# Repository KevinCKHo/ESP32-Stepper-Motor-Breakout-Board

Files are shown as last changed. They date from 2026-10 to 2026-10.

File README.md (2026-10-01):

# ESP32 Stepper Motor Breakout Board

A Wi-Fi controlled, 4-axis stepper motor controller built around an ESP32 on a custom breakout PCB. It was designed to drive a motorized microscope stage (the *Microscope Stage Mover*). 

The ESP32 creates its own Wi-Fi access point and serves a web dashboard. From the dashboard you can jog each axis with sliders, trigger an emergency stop, and watch temperature and humidity live.

<p align="center">
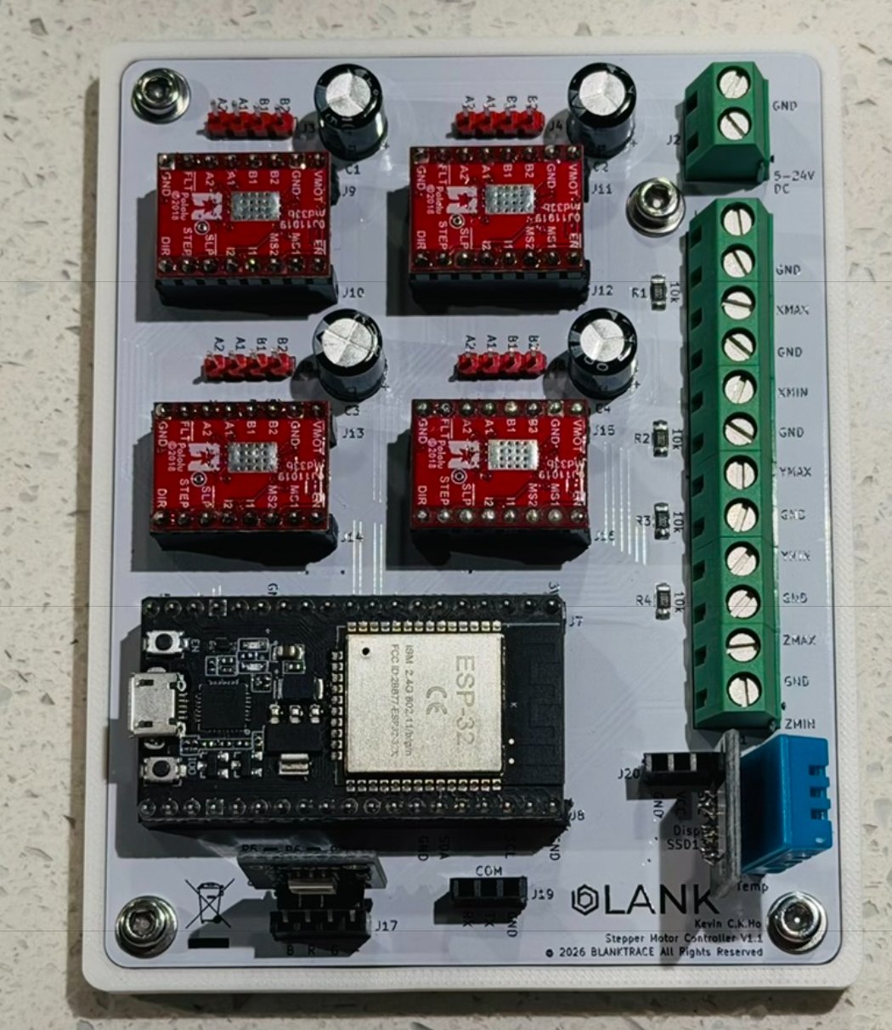
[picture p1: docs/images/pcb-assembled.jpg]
Assembled board with ESP32 and four MP6500 drivers
  
</p>

## Repository layout
| Folder | Contents |
|---|---|
| [`firmware/`](firmware) | PlatformIO project for the ESP32 (Arduino framework) |
| [`hardware/`](hardware) | KiCad 10 project for the *ESP32 Stepper Breakout Board* (schematic, PCB) |
| [`hardware/gerbers/`](hardware/gerbers) | Gerber and drill files (rev V1.1), ready to upload to a PCB fab |
| [`docs/images/`](docs/images) | Pinout, render, and board photos |

## Features
- Up to 4 stepper axes (X, Y, Z plus an optional 4th axis enabled from the UI) using Pololu-style **MP6500** driver carriers
- Variable speed and direction for each axis through slider control in the web UI
- 6 limit switches (X/Y/Z min and max) that stop motion in the triggered direction
- Software emergency stop
- **Thermal stop**: a DHT11 sensor halts all motors above 40 °C
- RGB status LED
- 5–24 V DC motor supply input on a screw terminal

## Hardware: ESP32 Stepper Breakout Board (V1.1)
An 85 × 110 mm, 2-layer board.

| JLCPCB render | Bare PCB |
|---|---|
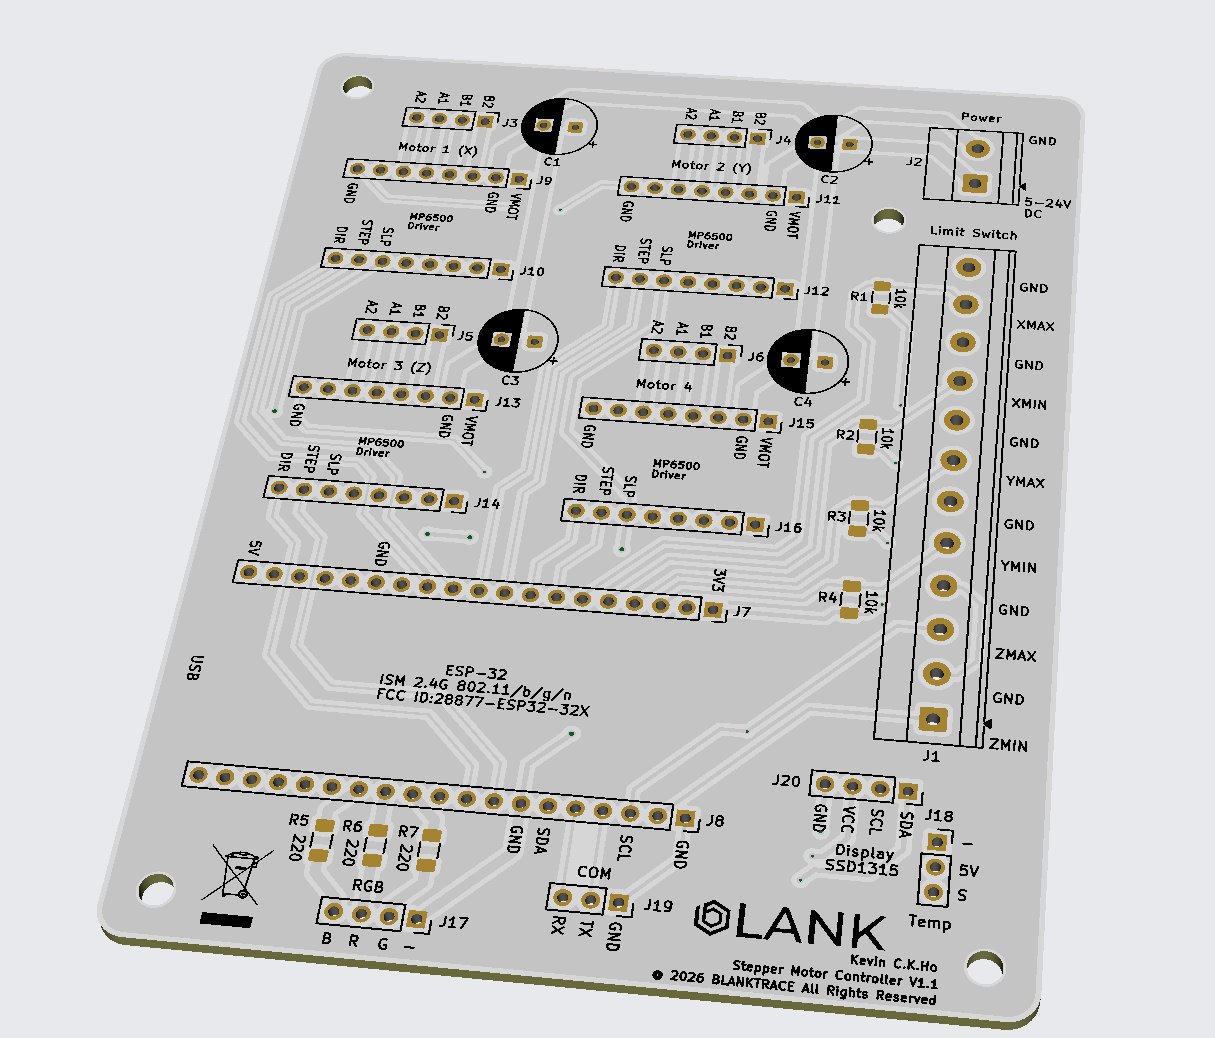
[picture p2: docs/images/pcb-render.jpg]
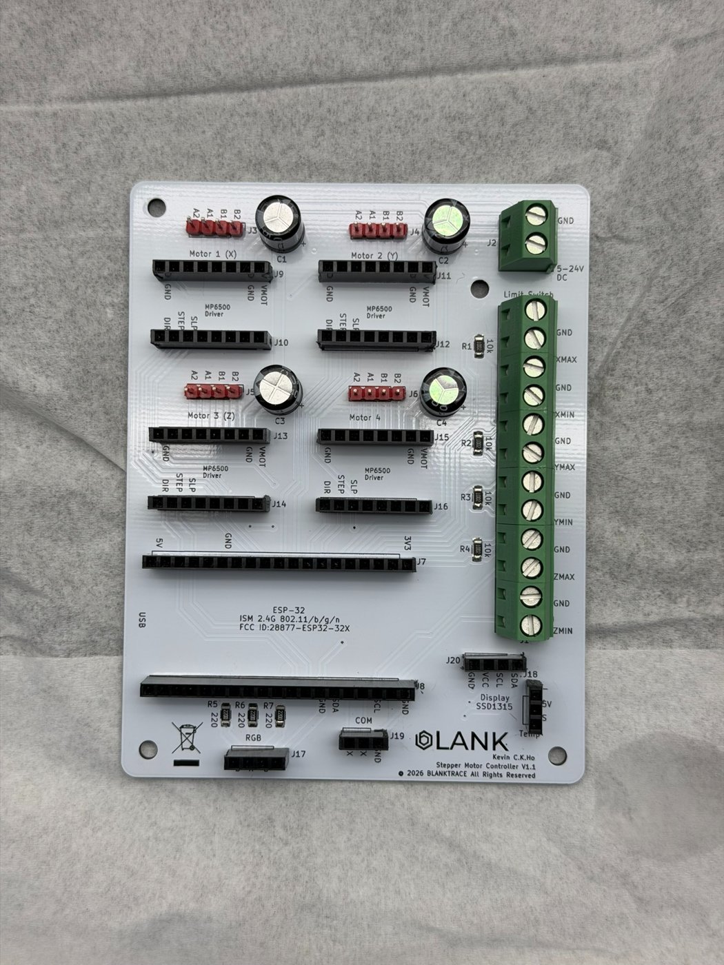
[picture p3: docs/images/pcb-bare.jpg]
|  |  |

**Main connectors**
| Ref | Function |
|---|---|
| J7, J8 | ESP32 DevKit (30-pin) sockets |
| J9–J16 | 4 × MP6500 driver sockets (Motor 1 X, Motor 2 Y, Motor 3 Z, Motor 4) |
| J3–J6 | Motor outputs (A2 A1 B1 B2) |
| C1–C4 | Bulk capacitors on VMOT for each driver |
| J2 | Motor power, 5–24 V DC |
| J1 | 12-way limit-switch terminal (switch to GND) |
| J17 | RGB LED (B R G −) with 220 Ω resistors R5–R7 |
| J18 | Temperature sensor (DHT11) |
| J19 | Serial COM (RX TX GND) |
| J20 | I²C display (SSD1315) |

R1–R4 are 10 kΩ pull-ups for limit inputs on GPIO 34/35/36/39. Those pins have no internal pull-ups.

### ESP32 pin map
ESP32 pin map

| Function | GPIO |
|---|---|
| Motor 1 (X): STEP / DIR | 27 / 14 |
| Motor 2 (Y): STEP / DIR | 25 / 26 |
| Motor 3 (Z): STEP / DIR | 19 / 18 |
| Motor 4: STEP / DIR | 32 / 33 |
| X MIN / X MAX | 34 / 35 |
| Y MIN / Y MAX | 36 (SVP) / 39 (SVN) |
| Z MIN / Z MAX | 23 / 22 |
| RGB LED: R / G / B | 16 / 17 / 4 |
| DHT11 data | 21 |
| I²C display SDA / SCL | 21 / 22 (shared with DHT11 and Z MAX) |

## Bill of materials
Also available as [`docs/BOM.csv`](docs/BOM.csv).

| Qty | Ref | Part | MPN / Source |
|---:|---|---|---|
| 1 | J7, J8 | ESP32 ESP-32D development board (30-pin DevKit) | [Amazon](https://www.amazon.com/dp/B0C8HDDNLV) |
| 4 | J9–J16 | MP6500 stepper motor driver carrier | [Pololu #2968](https://www.pololu.com/product/2968) |
| 1 | J18 | Keyes DHT11 temperature & humidity module | — |
| 1 | J17 | Keyes KY-009 3-colour RGB LED module | — |
| 4 | C1–C4 | 100 µF 50 V electrolytic capacitor | — |
| 4 | R1–R4 | 10 kΩ 1% ¼ W, 1206 (limit-switch pull-ups) | Stackpole RMCF1206FT10K0 |
| 3 | R5–R7 | 220 Ω 1% ¼ W, 1206 (RGB LED) | Stackpole RMCF1206FT220R |
| 1 | J1 | Terminal block, 12-pos, 5 mm, side entry | Phoenix Contact 1715129 |
| 1 | J2 | Terminal block, 2-pos, 5 mm, side entry | Phoenix Contact 1715022 |
| 2 | J7, J8 | Female header 1×19, 2.54 mm (ESP32 socket) | — |
| 8 | J9–J16 | Female header 1×8, 2.54 mm (driver sockets) | — |
| 2 | J17, J20 | Female header 1×4, 2.54 mm (RGB / display) | — |
| 2 | J18, J19 | Female header 1×3, 2.54 mm (temp sensor / COM) | — |
| 4 | J3–J6 | Male pin header 1×4, 2.54 mm (motor outputs) | — |

Optional: SSD1315 0.96" I²C OLED display on J20.

## Firmware
Built with [PlatformIO](https://platformio.org/) (VS Code extension).

1. Open the `firmware/` folder in VS Code with PlatformIO installed.
2. Connect the ESP32 over USB and click **Upload**.
3. On your phone or PC, join the Wi-Fi network **`ESP32-Stepper-System2`**. The password is set in `src/main.cpp`; change it before you deploy.
4. Browse to **http://192.168.4.1** to open the control dashboard.

Libraries (installed automatically): Adafruit DHT sensor library, Adafruit Unified Sensor.

## Ordering the PCB
Upload `hardware/gerbers/ESP32 Stepper break out board V1.1.zip` to JLCPCB, PCBWay, or any other fab. Default 2-layer, 1.6 mm settings are fine.

## Author
Kevin C.K. Ho, BLANKTRACE © 2026

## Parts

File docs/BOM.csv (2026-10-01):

Qty | Reference | Description | Manufacturer Part Number | Manufacturer | Link
1 | J7 J8 | ESP32 ESP-32D development board (30-pin DevKit) |  |  | https://www.amazon.com/dp/B0C8HDDNLV
4 | J9-J16 | MP6500 stepper motor driver carrier | 2968 | Pololu | https://www.pololu.com/product/2968
1 | J18 | DHT11 temperature & humidity sensor module | DHT11 | Keyes
1 | J17 | 3-colour RGB LED module | KY-009 | Keyes
4 | C1-C4 | 100 µF 50 V electrolytic capacitor
4 | R1-R4 | 10 kΩ 1% 1/4 W resistor 1206 (limit switch pull-ups) | RMCF1206FT10K0 | Stackpole
3 | R5-R7 | 220 Ω 1% 1/4 W resistor 1206 (RGB LED) | RMCF1206FT220R | Stackpole
1 | J1 | Terminal block 12-pos 5 mm side entry | 1715129 | Phoenix Contact
1 | J2 | Terminal block 2-pos 5 mm side entry | 1715022 | Phoenix Contact
2 | J7 J8 | Female header 1x19 2.54 mm (ESP32 socket)
8 | J9-J16 | Female header 1x8 2.54 mm (driver sockets)
2 | J17 J20 | Female header 1x4 2.54 mm (RGB / display)
2 | J18 J19 | Female header 1x3 2.54 mm (temp sensor / COM)
4 | J3-J6 | Male pin header 1x4 2.54 mm (motor outputs)

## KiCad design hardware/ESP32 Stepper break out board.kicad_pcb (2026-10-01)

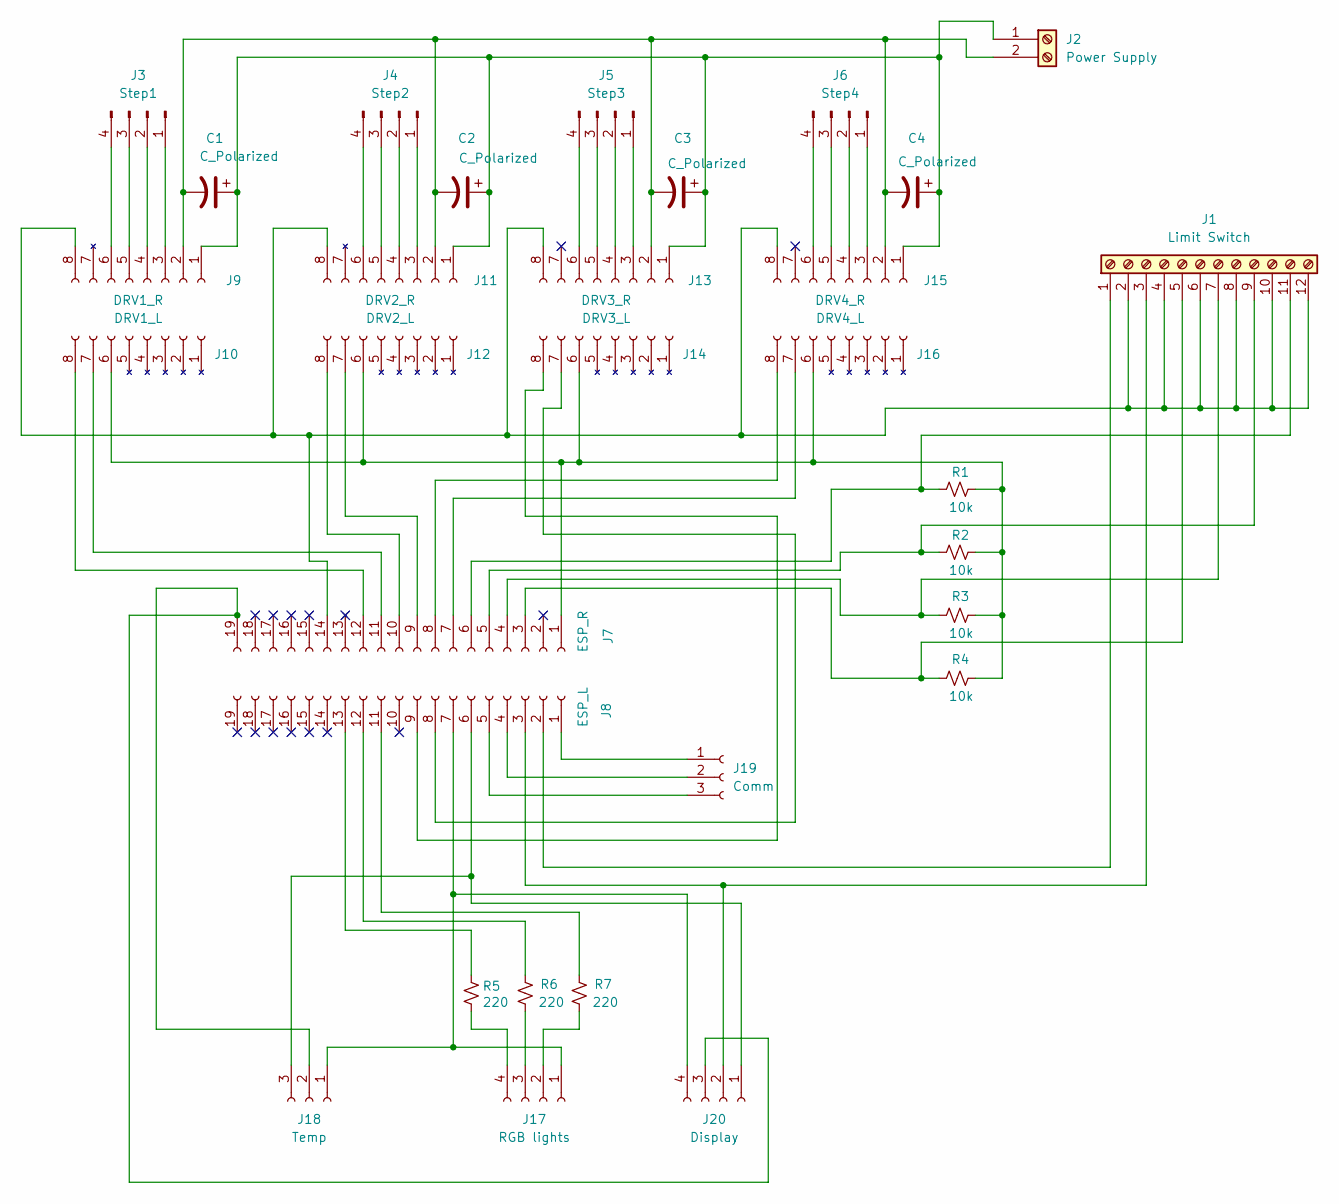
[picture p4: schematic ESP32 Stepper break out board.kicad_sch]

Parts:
C1, C2, C3, C4: C_Polarized; CP_Radial_D8.0mm_P3.50mm
J1: Limit Switch; TerminalBlock_Phoenix_MKDS-1,5-12_1x12_P5.00mm_Horizontal
J2: Power Supply; TerminalBlock_Phoenix_MKDS-1,5-2_1x02_P5.00mm_Horizontal
J3: Step1; PinHeader_1x04_P2.54mm_Vertical
J4: Step2; PinHeader_1x04_P2.54mm_Vertical
J5: Step3; PinHeader_1x04_P2.54mm_Vertical
J6: Step4; PinHeader_1x04_P2.54mm_Vertical
J7: ESP_R; PinSocket_1x19_P2.54mm_Vertical
J8: ESP_L; PinSocket_1x19_P2.54mm_Vertical
J9: DRV1_R; PinSocket_1x08_P2.54mm_Vertical
J10: DRV1_L; PinSocket_1x08_P2.54mm_Vertical
J11: DRV2_R; PinSocket_1x08_P2.54mm_Vertical
J12: DRV2_L; PinSocket_1x08_P2.54mm_Vertical
J13: DRV3_R; PinSocket_1x08_P2.54mm_Vertical
J14: DRV3_L; PinSocket_1x08_P2.54mm_Vertical
J15: DRV4_R; PinSocket_1x08_P2.54mm_Vertical
J16: DRV4_L; PinSocket_1x08_P2.54mm_Vertical
J17: RGB lights; PinSocket_1x04_P2.54mm_Vertical
J18: Temp; PinSocket_1x03_P2.54mm_Vertical
J19: Comm; PinSocket_1x03_P2.54mm_Vertical
J20: Display; PinSocket_1x04_P2.54mm_Vertical
R1, R2, R3, R4: 10k; R_1206_3216Metric_Pad1.30x1.75mm_HandSolder
R5, R6, R7: 220; R_1206_3216Metric_Pad1.30x1.75mm_HandSolder

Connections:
unnamed: J1.11 (xmax), J7.6 (P35_XMAX), R1.2
unnamed: J1.9 (xmin), J7.5 (P34_XMIN), R2.2
unnamed: J1.7 (ymax), J7.4 (SVN_YMAX), R3.2
unnamed: J1.5 (ymin), J7.3 (SVP_YMIN), R4.2
unnamed: J1.3 (zmax), J8.3 (P22_zmax), J20.2 (SCL)
unnamed: J1.1 (zmin), J8.2 (P23_zmin)
unnamed: J3.1, J9.3 (B2)
unnamed: J3.2, J9.4 (B1)
unnamed: J3.3, J9.5 (A1)
unnamed: J3.4, J9.6 (A2)
unnamed: J8.13 (P4_B), R5.1
unnamed: J8.12 (P16_R), R6.1
unnamed: J8.11 (P17_G), R7.1
unnamed: J7.12 (P14_DIR-1), J10.8 (DIR)
unnamed: J7.1 (3V3), J10.6 (SLP), J12.6 (SLP), J14.6 (SLP), J16.6 (SLP), R1.1, R2.1, R3.1, R4.1
unnamed: J7.11 (P27_STEP-1), J10.7 (STEP)
unnamed: J4.3, J11.5 (A1)
unnamed: J4.4, J11.6 (A2)
unnamed: J4.2, J11.4 (B1)
unnamed: J4.1, J11.3 (B2)
unnamed: C1.1, C2.1, C3.1, C4.1, J2.1 (GND), J9.1 (VMOT), J11.1 (VMOT), J13.1 (VMOT), J15.1 (VMOT)
unnamed: J7.10 (P26_DIR-2), J12.8 (DIR)
unnamed: J7.9 (P25_STEP-2), J12.7 (STEP)
unnamed: J5.3, J13.5 (A1)
unnamed: J5.4, J13.6 (A2)
unnamed: J5.2, J13.4 (B1)
unnamed: J5.1, J13.3 (B2)
unnamed: C1.2, C2.2, C3.2, C4.2, J2.2 (5-24V), J9.2 (GND), J11.2 (GND), J13.2 (GND), J15.2 (GND)
unnamed: J1.2 (GND), J1.4 (GND), J1.6 (GND), J1.8 (GND), J1.10 (GND), J1.12 (GND), J7.14 (GND), J9.8, J11.8 (GND), J13.8, J15.8
unnamed: J8.9 (P18_DIR-3), J14.8 (DIR)
unnamed: J8.8 (P19_STEP3), J14.7 (STEP)
unnamed: J6.3, J15.5 (A1)
unnamed: J6.4, J15.6 (A2)
unnamed: J6.2, J15.4 (B1)
unnamed: J6.1, J15.3 (B2)
unnamed: J7.8 (P33_DIR-4), J16.8 (DIR)
unnamed: J7.7 (P32_STEP-4), J16.7 (STEP)
unnamed: J8.7 (GND), J17.1 (-), J18.1 (-), J20.4 (GND)
unnamed: J17.4 (B), R5.2
unnamed: J17.2 (G), R7.2
unnamed: J17.3 (R), R6.2
unnamed: J7.19 (5V), J18.2 (5V), J20.3 (VCC)
unnamed: J8.6 (P21), J18.3 (S), J20.1 (SDA)
unnamed: J8.1 (GND), J19.1 (GND)
unnamed: J8.5 (RX), J19.3 (RX)
unnamed: J8.4 (TX), J19.2 (TX)

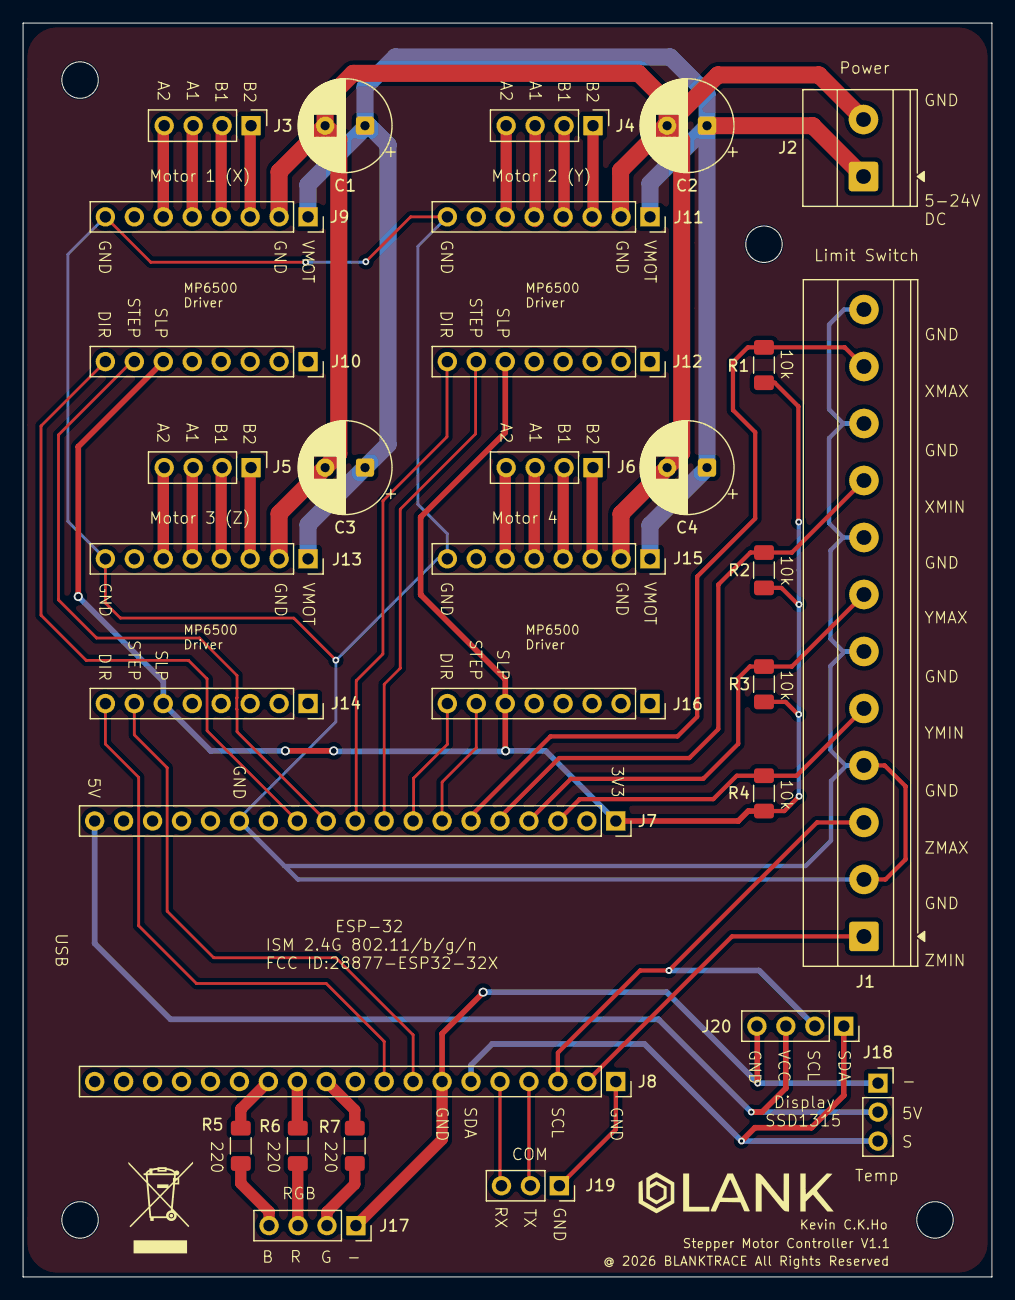
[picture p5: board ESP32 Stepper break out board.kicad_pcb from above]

Board: 2 copper layers, 85.0 x 110.0 mm, 31 parts (0 on the bottom side), 46 nets.

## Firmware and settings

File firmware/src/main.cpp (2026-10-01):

#include <WiFi.h>
#include <WebServer.h>
#include <DHT.h>

// --- DHT11 Environmental Sensor Configuration ---
#define DHTPIN 21          // DHT11 data pin connected to GPIO 4
#define DHTTYPE DHT11     // Defining the sensor type
DHT dht(DHTPIN, DHTTYPE); // Initialize DHT object

// --- RGB LED Pins for Visual Status Feedback LED Pins (B:21, R:22, G:23) ---
const int bluPin = 4;  // Blue channel
const int redPin = 16;  // Red channel (Emergency/Error)
const int grnPin = 17;  // Green channel (Ready/Normal)

// --- Wi-Fi Access Point Credentials ---
const char* ssid = "ESP32-Stepper-System2";   // Network name created by ESP32
const char* password = "12345678";           // Network password

// --- Motor 1 (X-Axis) Stepper Driver Pins ---
const int stepPin1 = 27; // PWM signal for speed
const int dirPin1  = 14; // High/Low signal for direction

// --- Motor 2 (Y-Axis) Stepper Driver Pins ---
const int stepPin2 = 25;
const int dirPin2  = 26;

// --- Motor 3 (Z-Axis) Stepper Driver Pins ---
const int stepPin3 = 19;
const int dirPin3  = 18;

// --- Motor 4 (Extra-Axis) Stepper Driver Pins ---
const int stepPin4 = 32;
const int dirPin4  = 33;

// --- Limit Switch Pins (Input Pullup used to detect Ground) ---
const int limXmin = 34; // Left limit
const int limXmax = 35; // Right limit
const int limYmin = 36; // Down limit
const int limYmax = 39; // Up limit
const int limZmin = 23; // Backward limit
const int limZmax = 22; // Forward limit

// --- PWM (Pulse Width Modulation) Configuration ---
const int res = 8;        // 8-bit resolution (0-255)
const int minFreq = 16;    
const int maxFreq = 1000;
const int chan1 = 0;  // Motor 1 uses Timer 0
const int chan2 = 2;  // Motor 2 uses Timer 1
const int chan3 = 4;  // Motor 3 uses Timer 2
const int chan4 = 6;  // Motor 4 uses Timer 3
int lastSVal1 = -1;
int lastSVal2 = -1;
int lastSVal3 = -1;
int lastSVal4 = -1;


WebServer server(80); // Initialize web server on port 80

// --- Global State Variables ---
bool virtualEmergencyStop = false; // Software kill-switch state
bool ledEnabled = true;            // User preference for status LED
bool thermalEmergencyStop = false; // NEW: Tracks if temperature is too high
int sVal1 = 90;                    // Motor 1 Slider value (90 = Stop)
int sVal2 = 90;                    // Motor 2 Slider value
int sVal3 = 90;                    // Motor 3 Slider value
int sVal4 = 90;                    // Motor 4 Slider value
bool motor4Enabled = false;        // Motor 4 is disabled by default
float currentTemp = 0;             // Last cached temperature
float currentHum = 0;              // Last cached humidity
unsigned long lastDHTRead = 0;     // Timing variable for DHT sensor

// --- RGB Helper Function: Updates the status light color ---
void setRGB(int r, int g, int b) {

  if (!ledEnabled) {               // If LED is toggled off in UI, kill all color
    analogWrite(redPin, 0);
    analogWrite(grnPin, 0);
    analogWrite(bluPin, 0);
    return;
  }
  analogWrite(redPin, r);
  analogWrite(grnPin, g);
  analogWrite(bluPin, b);
}

// ---------------------------------------------------------------------------
// HTML Interface
// ---------------------------------------------------------------------------
// --- Webpage Handler: Serves the HTML/JS Dashboard ---
void handleRoot() {

  // index_html contains the CSS for styling and JavaScript for AJAX updates
  // static: keeps this multi-KB string out of loopTask's stack (which caused a
  // stack-canary panic/reboot on every page load once the page grew past ~8KB)
  static const char index_html[] PROGMEM = R"rawliteral(

<!DOCTYPE html>
<html><head>
<title>Microscope Control</title>
<meta name="viewport" content="width=device-width,initial-scale=1.0">
<style>
/* Reset default margins and padding for a clean look */
*{box-sizing:border-box;margin:0;padding:0;}
/* Main background styling: Dark theme, centered content */
body{font-family:-apple-system,sans-serif;background:#1c1c1e;display:flex;justify-content:center;padding:20px;}
.shell{width:100%;max-width:390px;}
.card{background:rgba(44,44,46,0.95);border-radius:22px;padding:20px;margin-bottom:12px;border:0.5px solid rgba(255,255,255,0.1);}
.lbl{font-size:11px;font-weight:600;letter-spacing:.08em;text-transform:uppercase;color:rgba(255,255,255,0.4);margin-bottom:10px;}
.title{font-size:22px;font-weight:600;color:#fff;margin-bottom:16px;}
.speed{font-size:32px;font-weight:300;color:#fff;text-align:center;}
.spdsub{font-size:12px;color:rgba(255,255,255,0.35);text-align:center;margin-bottom:12px;}
input[type=range]{-webkit-appearance:none;width:100%;height:6px;background:rgba(255,255,255,0.12);border-radius:3px;outline:none;}
input[type=range]::-webkit-slider-thumb{-webkit-appearance:none;width:28px;height:28px;background:#fff;border-radius:50%;}
.tgl{width:51px;height:31px;border-radius:16px;border:none;float:right;}
.tgl.off{background:rgba(255,255,255,0.14);}
.tgl.on{background:#ff3b30;}
.tgl.led-on{background:#34c759;}
.swg{display:grid;grid-template-columns:1fr 1fr;gap:8px;}
.swp{border-radius:12px;padding:8px;text-align:center;background:rgba(255,255,255,0.07);font-size:10px;color:rgba(255,255,255,0.4);}
.swp.hit{background:rgba(255,59,48,0.2);color:#ff3b30;}
/* Temperature/Humidity Styles */
.env-grid{display:grid;grid-template-columns:1fr 1fr;gap:15px;text-align:center;}
.env-val{font-size:24px;font-weight:500;color:#ffffff;margin-top:5px;}
</style>
</head><body>
<div class="shell">
  <div class="card">
    <button class="tgl off" id="btnE" onclick="toggleE()"></button>
    <div class="title">Microscope</div>
    <div style="color:rgba(255,255,255,0.4);font-size:13px;" id="esub">System Armed</div>
  </div>
  <div class="card">
    <div class="lbl">Environment</div>
    <div class="env-grid">
      <div><div class="lbl">Temperature</div><div class="env-val" id="dispT">--°C</div></div>
      <div><div class="lbl">Humidity</div><div class="env-val" id="dispH">--%</div></div>
    </div>
  </div>
  <div class="card">
    <div class="lbl">Motor 1 (X-Axis)</div>
    <div class="speed" id="spd1">0</div>
    <div class="spdsub" id="dir1">Stopped</div>
    <input type="range" min="0" max="180" value="90" id="sl1" oninput="onSl(1,this.value)" onpointerup="rstSl(1)">
  </div>
  <div class="card">
    <div class="lbl">Motor 2 (Y-Axis)</div>
    <div class="speed" id="spd2">0</div>
    <div class="spdsub" id="dir2">Stopped</div>
    <input type="range" min="0" max="180" value="90" id="sl2" oninput="onSl(2,this.value)" onpointerup="rstSl(2)">
  </div>
  <div class="card">
    <div class="lbl">Motor 3 (Z-Axis)</div>
    <div class="speed" id="spd3">0</div>
    <div class="spdsub" id="dir3">Stopped</div>
    <input type="range" min="0" max="180" value="90" id="sl3" oninput="onSl(3,this.value)" onpointerup="rstSl(3)">
  </div>
  <div class="card">
    <button class="tgl off" id="btnM4" onclick="toggleM4()"></button>
    <div class="lbl">Motor 4 (Extra-Axis)</div>
    <div class="speed" id="spd4">0</div>
    <div class="spdsub" id="dir4">Disabled</div>
    <input type="range" min="0" max="180" value="90" id="sl4" disabled oninput="onSl(4,this.value)" onpointerup="rstSl(4)">
  </div>
  <div class="card">
    <div class="lbl">Limits</div>
    <div class="swg" id="swg">
      <div class="swp" id="xm">X MIN</div><div class="swp" id="xx">X MAX</div>
      <div class="swp" id="ym">Y MIN</div><div class="swp" id="yx">Y MAX</div>
      <div class="swp" id="zm">Z MIN</div><div class="swp" id="zx">Z MAX</div>
    </div>
    <div style="margin-top:20px; padding-top:15px; border-top:0.5px solid rgba(255,255,255,0.1);">
      <button class="tgl led-on" id="btnL" onclick="toggleLED()"></button>
      <div class="lbl" style="margin-top:8px;">Status LED</div>
    </div>
  </div>
</div>
<script>
let eOn = false;
let ledOn = true;
let m4On = false;
let limits = {xm:false, xx:false, ym:false, yx:false, zm:false, zx:false};
let moveCtrls = [null, null, null, null];
const dirLabels = {
  1: { fwd: 'Right',    rev: 'Left'      },
  2: { fwd: 'Up',       rev: 'Down'      },
  3: { fwd: 'Forward',  rev: 'Backward' },
  4: { fwd: 'Forward',  rev: 'Backward' }
};
function toggleE() {
  eOn = !eOn;
  document.getElementById('btnE').className = 'tgl ' + (eOn ? 'on' : 'off');
  fetch('/estop?active=' + (eOn ? '1' : '0'));
  const disabled = eOn;
  document.getElementById('sl1').disabled = disabled;
  document.getElementById('sl2').disabled = disabled;
  document.getElementById('sl3').disabled = disabled;
  document.getElementById('sl4').disabled = disabled || !m4On;
}
function toggleM4() {
  m4On = !m4On;
  document.getElementById('btnM4').className = 'tgl ' + (m4On ? 'on' : 'off');
  fetch('/motor4?enable=' + (m4On ? '1' : '0'));
  if (!m4On) {
    document.getElementById('sl4').value = 90;
    document.getElementById('spd4').textContent = '0';
  }
  document.getElementById('dir4').textContent = m4On ? 'Stopped' : 'Disabled';
  document.getElementById('sl4').disabled = eOn || !m4On;
}
function toggleLED() {
  ledOn = !ledOn;
  document.getElementById('btnL').className = 'tgl ' + (ledOn ? 'led-on' : 'off');
  fetch('/led?enable=' + (ledOn ? '1' : '0'));
}
function onSl(m, v) {
  if (eOn) return;
  if (m === 4 && !m4On) return;
  let val = parseInt(v);
  if (m === 1) {
    if (limits.xm && val < 90) val = 90;
    if (limits.xx && val > 90) val = 90;
  } else if (m === 2) {
    if (limits.ym && val < 90) val = 90;
    if (limits.yx && val > 90) val = 90;
  } else if (m === 3) {
    if (limits.zm && val < 90) val = 90;
    if (limits.zx && val > 90) val = 90;
  }
  document.getElementById('sl' + m).value = val;
  const db = (val >= 88 && val <= 92);
  const lbl = dirLabels[m];
  document.getElementById('spd'+m).textContent = db ? '0' : Math.round(Math.abs(val-90)/90*100);
  document.getElementById('dir'+m).textContent = db ? 'Stopped' : (val > 90 ? lbl.fwd : lbl.rev);
  if (moveCtrls[m-1]) moveCtrls[m-1].abort();
  moveCtrls[m-1] = new AbortController();
  fetch(`/move?m=${m}&v=${val}`, { signal: moveCtrls[m-1].signal });
}
function rstSl(m) {
  document.getElementById('sl'+m).value = 90;
  onSl(m, 90);
}
setInterval(() => {
  fetch('/status').then(r => r.json()).then(d => {
    limits = d;
    ['xm','xx','ym','yx','zm','zx'].forEach(k => {
      document.getElementById(k).className = 'swp ' + (d[k] ? 'hit' : '');
    });
    document.getElementById('dispT').textContent = d.t + "°C";
    document.getElementById('dispH').textContent = d.h + "%";
    // Update the UI text to show WHY the system is locked
    const sub = document.getElementById('esub');
    if (d.therm) {
      sub.textContent = "OVERHEAT LOCKOUT";
      sub.style.color = "#ff3b30";
    } else {
      sub.textContent = eOn ? "Manual E-Stop" : "System Armed";
      sub.style.color = "rgba(255,255,255,0.4)";
    }

    // Disable sliders if thermal lock is active
    const lockout = eOn || d.therm;
    document.getElementById('sl1').disabled = lockout;
    document.getElementById('sl2').disabled = lockout;
    document.getElementById('sl3').disabled = lockout;
    document.getElementById('sl4').disabled = lockout || !m4On;
  });
}, 50);
</script>
</body></html>
  )rawliteral";
  server.send(200, "text/html; charset=utf-8", index_html);
}

// --- API Handler: Receives movement commands from the UI sliders ---
void handleMove() {
  if (server.hasArg("m") && server.hasArg("v")) {
    int motor = server.arg("m").toInt();    // Which motor (1, 2, or 3)
    int val = server.arg("v").toInt();      // Slider value (0 to 180)
    if (motor == 1) sVal1 = val;
    if (motor == 2) sVal2 = val;
    if (motor == 3) sVal3 = val;
    if (motor == 4 && motor4Enabled) sVal4 = val;
    server.send(200, "text/plain", "OK");
  }
}

// --- API Handler: Motor 4 Enable/Disable Toggle ---
void handleMotor4() {
  if (server.hasArg("enable")) {
    motor4Enabled = (server.arg("enable") == "1");
    if (!motor4Enabled) sVal4 = 90; // Force stop when disabled
    server.send(200, "text/plain", "OK");
  }
}

// --- API Handler: Virtual E-Stop Toggle ---
void handleEStop() {
  if (server.hasArg("active")) {
    virtualEmergencyStop = (server.arg("active") == "1");
    server.send(200, "text/plain", "OK");
  }
}

// --- API Handler: LED Toggle ---
void handleLED() {
  if (server.hasArg("enable")) {
    ledEnabled = (server.arg("enable") == "1");
    server.send(200, "text/plain", "OK");
  }
}

// --- API Handler: Sends Limit Switch & Sensor data as JSON to the UI ---
void handleStatus() {
  String j = "{";
  j += "\"xm\":" + String(digitalRead(limXmin) == LOW ? "true":"false") + ",";
  j += "\"xx\":" + String(digitalRead(limXmax) == LOW ? "true":"false") + ",";
  j += "\"ym\":" + String(digitalRead(limYmin) == LOW ? "true":"false") + ",";
  j += "\"yx\":" + String(digitalRead(limYmax) == LOW ? "true":"false") + ",";
  j += "\"zm\":" + String(digitalRead(limZmin) == LOW ? "true":"false") + ",";
  j += "\"zx\":" + String(digitalRead(limZmax) == LOW ? "true":"false") + ",";
  j += "\"t\":" + String(currentTemp, 1) + ",";
  j += "\"h\":" + String(currentHum, 1) + ",";
  j += "\"therm\":" + String(thermalEmergencyStop ? "true" : "false") + "}"; // Added this
  server.send(200, "application/json", j);
}

void setup() {
  dht.begin();

  // Pin Mode Definitions
  pinMode(redPin, OUTPUT);
  pinMode(grnPin, OUTPUT);
  pinMode(bluPin, OUTPUT);
  pinMode(dirPin1, OUTPUT);
  pinMode(dirPin2, OUTPUT);
  pinMode(dirPin3, OUTPUT);
  pinMode(dirPin4, OUTPUT);

  // Setup limit switches with Internal Pullup (Triggered when connected to GND)
  pinMode(limXmin, INPUT_PULLUP); pinMode(limXmax, INPUT_PULLUP);
  pinMode(limYmin, INPUT_PULLUP); pinMode(limYmax, INPUT_PULLUP);
  pinMode(limZmin, INPUT_PULLUP); pinMode(limZmax, INPUT_PULLUP);
 
  // Initialize ESP32 High-Speed PWM (LEDC) for motor stepping
  ledcSetup(chan1, 1000, res); ledcAttachPin(stepPin1, chan1);
  ledcSetup(chan2, 1000, res); ledcAttachPin(stepPin2, chan2);
  ledcSetup(chan3, 1000, res); ledcAttachPin(stepPin3, chan3);
  ledcSetup(chan4, 1000, res); ledcAttachPin(stepPin4, chan4);

  // Start Wi-Fi Access Point and Web Server
  WiFi.softAP(ssid, password);
  server.on("/", handleRoot);
  server.on("/move", handleMove);
  server.on("/estop", handleEStop);
  server.on("/led", handleLED);
  server.on("/status", handleStatus);
  server.on("/motor4", handleMotor4);
  server.begin();
}



void loop() {
  server.handleClient();

  // --- DHT Reading ---
  if (millis() - lastDHTRead >= 1000) {
    lastDHTRead = millis();
    float t = dht.readTemperature();
    float h = dht.readHumidity();
    if (!isnan(t) && !isnan(h)) { currentTemp = t; currentHum = h; thermalEmergencyStop = (currentTemp > 40.0);}
  }

// --- MASTER STOP LOGIC ---
// Combine the UI E-Stop and the Thermal E-Stop
bool masterStop = (virtualEmergencyStop || thermalEmergencyStop);

  // --- Limit & E-Stop Status ---
bool anyLimit = (digitalRead(limXmin)==LOW || digitalRead(limXmax)==LOW ||
                   digitalRead(limYmin)==LOW || digitalRead(limYmax)==LOW ||
                   digitalRead(limZmin)==LOW || digitalRead(limZmax)==LOW);

  if (virtualEmergencyStop) setRGB(255, 0, 0);
  else if (anyLimit) setRGB(255, 100, 0);
  else setRGB(0, 255, 0);

 // --- Motor Processing Lambda ---
auto processMotor = [](int ch, int dp, int& sv, int& lastSv, bool lMin, bool lMax, bool stop, int motorID) {
  bool inNeutral = (sv >= 88 && sv <= 92);
  bool limitHit = (lMin && sv < 90) || (lMax && sv > 90);

  // 1. Handle Stops (Emergency, Limit, or Neutral)
  if (stop || limitHit || inNeutral) {
    if (lastSv != 90) { 
      ledcWrite(ch, 0); 
      lastSv = 90;
    }
    if (!stop && limitHit) sv = 90; 
    return;
  }

  // 2. Handle Movement (Only if value changed)
  if (sv != lastSv) {
    // This line flips Y (ID 2) and Z (ID 3) directions 
    // while keeping X (ID 1) the same.
    bool direction = (motorID == 2) ? (sv < 90) : (sv > 90);

    digitalWrite(dp, direction);

    int freq = map(abs(sv - 90), 1, 90, minFreq, maxFreq);
    ledcWriteTone(ch, freq);
    ledcWrite(ch, 128); 
    lastSv = sv; 
  }
};

  // Run for all motors
  processMotor(chan1, dirPin1, sVal1, lastSVal1, digitalRead(limXmin)==LOW, digitalRead(limXmax)==LOW, masterStop, 1);
  processMotor(chan2, dirPin2, sVal2, lastSVal2, digitalRead(limYmin)==LOW, digitalRead(limYmax)==LOW, masterStop, 2);
  processMotor(chan3, dirPin3, sVal3, lastSVal3, digitalRead(limZmin)==LOW, digitalRead(limZmax)==LOW, masterStop, 3);
  // Motor 4 has no limit switches; it is also stopped whenever it is disabled
  processMotor(chan4, dirPin4, sVal4, lastSVal4, false, false, masterStop || !motor4Enabled, 4);
}

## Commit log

2026-10-01 Add firmware Pre-release V6, KiCad PCB V1.1, gerbers and docs
    Restructure repo into firmware/, hardware/ and docs/ folders.
    Claude-Session: https://claude.ai/code/session_013XrW36o9eMf22KVJ7Zmeon
    [ESP32 Stepper break out board.kicad_pcb, ESP32 Stepper break out board.kicad_sch]
2026-10-01 README: rename project to ESP32 Stepper Motor Breakout Board
    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
2026-10-01 Add bill of materials (README table + docs/BOM.csv)
    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
    [BOM.csv]
2026-10-01 Replace pinout screenshot with colour-coded SVG pin map
    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
2026-10-01 Update KiCad render reference to JLCPCB

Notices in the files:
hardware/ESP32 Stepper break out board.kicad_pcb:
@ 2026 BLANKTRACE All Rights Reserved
